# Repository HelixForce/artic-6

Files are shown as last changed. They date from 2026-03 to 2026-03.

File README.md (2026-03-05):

# ARTIC-6 — Voice-Controlled 6-DOF Robotic Arm

> A fully scratch-designed 6-axis robotic arm with 720mm reach, 1kg payload, and natural voice control — built entirely from aluminum plate, stepper motors, and open-source software. No cloud APIs. No subscriptions. Everything runs locally.

<!-- TODO: Replace this line with a screenshot of your Fusion 360 full assembly -->
<!-- ![ARTIC-6 Assembly](docs/render.png) -->






---

## Why ARTIC-6?

Most DIY robot arms top out at 300mm reach with hobby servos that can barely lift a marker. ARTIC-6 is designed for **real tasks** — 720mm of reach and 1kg of payload capacity using industrial NEMA 23 steppers with 10:1 belt reductions. The arm understands plain English commands through local speech recognition and executes them using depth-camera vision and inverse kinematics. No cloud, no API keys, no monthly costs.

---

## Hardware Specs

| Spec | Value |
|---|---|
| Degrees of Freedom | 6 |
| Max Reach | 720mm |
| Payload | 1kg |
| Link 1 (Upper Arm) | 350mm — sandwich: 2× 3mm 6061-T6 Al + 40mm standoffs |
| Link 2 (Forearm) | 280mm — sandwich: 2× 3mm 6061-T6 Al + 40mm standoffs |
| Base Footprint | 250 × 250mm |
| Axes 1-3 Motors | NEMA 23, 1.9Nm, 2.8A + 10:1 GT2 belt reduction |
| Axes 4-6 Motors | NEMA 17, 59Ncm, 2A |
| Drivers | 6× TMC2209 V1.3 (StallGuard + StealthChop) |
| Controller | Arduino Mega 2560 (real-time pulse generation) |
| Brain | Raspberry Pi 5 4GB (motion planning + AI) |
| Base Bearing | 51100 thrust bearing + 608ZZ radial |
| Safety | NC limit switches, hardware E-stop, ±170° hard stops |

---

## Software Stack — 100% Local

```
Voice → Whisper (STT) → Ollama + Llama 3.3 (LLM) → ROS2 + MoveIt2 (IK)
                                    ↑
                    Intel RealSense D435 → YOLO v8 (object detection)
                                    ↓
              Arduino Mega → 6× TMC2209 → 6 Stepper Motors → ARM MOVES
```

Zero cloud. Zero API keys. Zero monthly cost.

---

## Wiring Diagram

Wiring Diagram

[Detailed Wiring & Safety Strategy](./docs/wiring_diagram.pdf) | Full wiring details: [docs/wiring_diagram.md](docs/wiring_diagram.md)

---

## Repository Structure

```
artic-6/
├── bom.csv                 ← Bill of materials with direct shopping links
├── README.md               ← You are here
├── cad/
│   ├── baseplate.dxf       ← 250×250mm base plate (SendCutSend)
│   ├── link1_upper_arm.dxf ← 350mm upper arm plate (order 2×)
│   ├── link2_forearm.dxf   ← 280mm forearm plate (order 2×)
│   ├── thrust_bearing_collar.stl ← 3D print (PETG)
│   └── generate_*.py       ← Python scripts to regenerate CAD files
├── docs/
│   ├── bom.md              ← Detailed BOM with specs and notes
│   ├── build_journal.md    ← Chronological progress log
│   ├── wiring_diagram.md   ← Full wiring strategy
│   ├── wiring_diagram.svg  ← Visual wiring diagram
│   ├── engineering_notes.md← Design decisions and failure analysis
│   └── arm_layout_visual.html ← Interactive arm diagram
├── firmware/
│   └── artic6_firmware/    ← Arduino Mega code (AccelStepper)
│       ├── artic6_firmware.ino
│       ├── config.h        ← Pin defs, speeds, joint limits
│       ├── stepper.h       ← Motor control
│       ├── homing.h        ← Limit switch homing
│       └── serial_protocol.h ← Serial command interface
└── software/               ← Python + ROS2 (in progress)
```

---

## Firmware — Serial Command Interface

The firmware is written and ready to upload. Commands over USB serial at 115200 baud:

```
PING                    → OK PONG
ENABLE                  → OK motors enabled
HOME                    → OK HOME complete
MOVE 2 45.0             → OK MOVE 2 → 45.00  (shoulder to 45°)
MOVA 0 45 -30 0 0 0     → OK MOVA             (all 6 axes)
POS                     → POS 0.00 45.00 -30.00 0.00 0.00 0.00
ESTOP                   → OK ESTOP activated
```

Full command reference: [firmware/README.md](firmware/README.md)

---

## Current Status

| Phase | Status |
|---|---|
| Planning & Engineering Review | ✅ Complete |
| CAD — Flat plates (base, links) | ✅ Generated, audited, imported to Fusion 360 |
| CAD — Joint brackets & motor mounts | 🔄 In progress |
| CAD — Full .STEP assembly | 🔄 In progress |
| Firmware v0.1 | ✅ Complete — AccelStepper, homing, serial protocol |
| Parts ordering | ⏳ Waiting on funds |
| Assembly | ⏳ Pending |
| Software (Python + ROS2) | ⏳ Not started |

---

## Budget

| Category | Cost |
|---|---|
| Motors + Drivers | $84 |
| Gear Reduction (pulleys + belt) | $29 |
| Compute + Electronics | $100 |
| Structure + Hardware (incl. SendCutSend) | $236 |
| Vision + Sensing | $101 |
| Filament (PETG + TPU) | $44 |
| Wiring + Cable Management | $28 |
| **Core Parts Total** | **$622** |
| Tools, shipping, tax, spares | ~$366-$802 |
| **Realistic All-In** | **$988 – $1,424** |

Full BOM with shopping links: [bom.csv](bom.csv) | Detailed specs: [docs/bom.md](docs/bom.md)

---

## Bill of Materials (Summary)

| Qty | Part | Unit ($) | Total ($) |
|-----|---|---|---|
| 3 | NEMA 23 Stepper 1.9Nm 2.8A 8mm shaft | 12 | 36 |
| 3 | NEMA 17 Stepper 2A 59Ncm | 8 | 24 |
| 8 | TMC2209 V1.3 Driver (BTT/Fysetc) | 3 | 24 |
| 4 | GT2 20T Pulley 8mm bore | 1.50 | 6 |
| 2 | GT2 60T Pulley 8mm bore | 3 | 6 |
| 2 | GT2 80T Pulley 8mm bore | 4 | 8 |
| 5m | GT2 Belt PU+steel core 6mm | 1.20 | 6 |
| 1 | Raspberry Pi 5 4GB | 60 | 60 |
| 1 | Arduino Mega 2560 | 8 | 8 |
| 1 | 24V 10A PSU | 12 | 12 |
| 1 | SendCutSend aluminum cutting | 130 | 130 |
| 20 | M5×40mm Hex Standoffs | 0.80 | 16 |
| 20 | 608ZZ Bearings | 0.25 | 5 |
| 2 | 51100 Thrust Bearings | 2 | 4 |
| 1 | RealSense D435 (used, optional) | 90 | 90 |
| — | *All other parts (switches, wire, caps, etc.)* | — | 187 |
| | **Total** | | **$622** |

> Full BOM with direct shopping links: [`bom.csv`](bom.csv)

---

## Documentation

- [Bill of Materials (CSV)](bom.csv) — Every part with qty, price, and shopping link
- [Bill of Materials (detailed)](docs/bom.md) — Full specs, notes, and warnings
- [Build Journal](docs/build_journal.md) — Chronological progress log
- [Wiring Diagram (PDF)](docs/wiring_diagram.pdf) — Printable wiring & safety strategy
- [Wiring Diagram (text)](docs/wiring_diagram.md) — Power zones, star ground, signal chain
- [Engineering Notes](docs/engineering_notes.md) — Lessons learned, failure analysis
- [Firmware README](firmware/README.md) — Setup guide and full command reference

---

## License

MIT License — see [LICENSE](LICENSE)

---

## Author

High school student building a 6-DOF robot arm from scratch for [Hack Club Blueprint](https://hackclub.com/blueprint/).

---

*Built with aluminum, stepper motors, and zero cloud APIs.*

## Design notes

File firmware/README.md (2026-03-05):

# Firmware

Arduino Mega 2560 stepper control code for the ARTIC-6 robot arm.

---

## Setup Instructions

### 1. Install Arduino IDE
Download from [arduino.cc](https://www.arduino.cc/en/software) — use version 2.x.

### 2. Install AccelStepper Library
In Arduino IDE: **Sketch → Include Library → Manage Libraries** → search **"AccelStepper"** by Mike McCauley → **Install**

### 3. Configure Board
- **Tools → Board → Arduino Mega or Mega 2560**
- **Tools → Processor → ATmega2560**
- **Tools → Port → (your COM port)**

### 4. Upload
Open `artic6_firmware/artic6_firmware.ino` → click Upload (→ button).

### 5. Test
Open **Serial Monitor** (magnifying glass icon), set **115200 baud** and **Newline** line ending:
```
Type: PING
Response: OK PONG
```

---

## File Structure

```
firmware/
├── artic6_firmware/
│   ├── artic6_firmware.ino   ← Main sketch (upload this)
│   ├── config.h              ← Pin definitions, speeds, limits, ratios
│   ├── stepper.h             ← Motor control (AccelStepper wrapper)
│   ├── homing.h              ← Limit switch homing sequences
│   └── serial_protocol.h     ← Command parser (RPi ↔ Arduino)
└── README.md                 ← You are here
```

---

## Serial Command Reference

Send commands from RPi (or Serial Monitor) at 115200 baud. Each command is a line ending with `\n`.

| Command | Example | What It Does |
|---|---|---|
| `PING` | `PING` | Heartbeat check → responds `OK PONG` |
| `ENABLE` | `ENABLE` | Energize all motors (they hold position) |
| `DISABLE` | `DISABLE` | De-energize all motors (arm goes limp) |
| `HOME` | `HOME` | Home all 6 axes in safe order |
| `HOMEA <axis>` | `HOMEA 2` | Home single axis (1-6) |
| `MOVE <axis> <deg>` | `MOVE 2 45.0` | Move axis to absolute angle |
| `MOVR <axis> <deg>` | `MOVR 3 -10.5` | Move axis by relative amount |
| `MOVA <a1-a6>` | `MOVA 0 45 -30 0 0 0` | Move all 6 axes simultaneously |
| `POS` | `POS` | Report current joint angles |
| `STATUS` | `STATUS` | Report e-stop, homing, motion state |
| `STOP` | `STOP` | Decelerate all axes to stop |
| `ESTOP` | `ESTOP` | Emergency stop (instant, disables motors) |
| `RESET` | `RESET` | Clear e-stop state (re-home required) |

### Typical Startup Sequence
```
PING          → OK PONG
ENABLE        → OK motors enabled
HOME          → OK HOME complete  (takes ~30 seconds)
MOVE 2 45     → OK MOVE 2 → 45.00
POS           → POS 0.00 45.00 0.00 0.00 0.00 0.00
```

### Response Format
- `OK ...` — command succeeded
- `ERR ...` — command failed (reason given)
- `WARN ...` — non-fatal warning (e.g., limit switch hit)
- `POS ...` — position data
- `STATUS ...` — status data

---

## Hardware Connections

| Arduino Pin | Function | Connected To |
|---|---|---|
| D2-D7 | STEP signals | TMC2209 #1-6 STEP |
| D8-D13 | DIR signals | TMC2209 #1-6 DIR |
| D22-D27 | EN signals | TMC2209 #1-6 EN |
| D28-D33 | Limit switches | KW11-3Z NC terminals |
| A0 | HX711 DOUT | Load cell amplifier |
| A1 | HX711 SCK | Load cell amplifier |
| Serial (USB) | Commands | Raspberry Pi 5 |

---

## How It Works

1. **On power-up:** All motors are disabled (free-spinning). Firmware waits for commands.
2. **ENABLE:** Motors energize and hold position. Arm is stiff but doesn't know where it is.
3. **HOME:** Each axis slowly moves toward its limit switch, backs off, re-approaches slowly for precision, then moves to a known offset. Now the firmware knows exactly where each joint is.
4. **MOVE:** AccelStepper calculates a smooth acceleration/deceleration profile and generates step pulses. The TMC2209 driver converts each pulse into a motor microstep.
5. **Safety:** Limit switches are checked every 100ms during motion. If one triggers, that axis stops immediately. E-stop cuts all motors.

---

## Tuning Guide

All tunable parameters are in `config.h`:

| Parameter | What to Change | When |
|---|---|---|
| `MAX_SPEED_x` | Increase for faster motion | If motors don't skip steps |
| `MAX_ACCEL_x` | Increase for snappier response | If motors don't skip steps |
| `MICROSTEPS` | 8→16 for smoother, 8→4 for faster | Trade smoothness vs speed |
| `REDUCTION_x` | Match your actual pulley ratios | After measuring real hardware |
| `HOME_OFFSETS` | Adjust zero position | After assembly |
| `JOINT_MIN/MAX` | Expand/shrink range of motion | After testing physical limits |

**If a motor skips steps** (makes grinding/clicking noise): reduce `MAX_SPEED` and `MAX_ACCEL` for that axis.

---

## Future: TMC2209 UART Configuration

Not yet implemented. Each TMC2209 needs UART for:
- Setting motor current limit (instead of potentiometer)
- StallGuard4 sensorless homing (backup to limit switches)
- CoolStep power savings

This will be added after basic motion works.

---

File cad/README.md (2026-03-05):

# CAD Files

This folder will contain Fusion 360 project files and DXF exports for SendCutSend.

---

## Planned Files

After Fusion 360 design sessions:

```
cad/
├── artic6.f3d              ← Main Fusion 360 project file
├── base_plate.dxf          ← 250×250mm, thrust bearing seat, slotted motor holes
├── link1_upper_arm.dxf     ← 350mm sandwich plate (make 2)
├── link2_forearm.dxf       ← 280mm sandwich plate (make 2)
├── joint_brackets.dxf      ← Shoulder + elbow pivots
├── motor_mounts.dxf        ← Aluminum L-brackets with slotted holes
└── screenshots/            ← Progress images for documentation
```

---

## CAD Session Order

1. **Base plate** — 250×250mm, slotted NEMA 23 holes, thrust bearing seat (24.5mm OD, 0.5mm deep), cable slot, PSU/electronics mounts, fan bracket, hard stop tabs
2. **Link 1 sandwich plates** (make 2 identical) — 350mm, 8mm pivot holes, M5 standoff holes every 100mm, cable channel, calibration marks at 100mm + 250mm
3. **Link 2 sandwich plates** (make 2 identical) — 280mm, same approach, RealSense strain relief slot
4. **Joint brackets** — shoulder + elbow pivots, hard stop tabs integrated
5. **Motor mounts** — aluminum L-brackets, slotted holes, NEMA 23 bolt pattern (47mm bolt circle, 4× M4)

---

## Key Constraints

| Feature | Dimension | Notes |
|---|---|---|
| Bearing holes | 8.1mm | 8mm + 0.1mm clearance |
| Bolt clearance | nominal + 0.2mm | |
| Slotted holes | 8mm × 14mm | For belt tensioning |
| Thrust bearing seat | 24.5mm OD, 0.5mm deep | NOT 26mm |
| Standoff spacing | Every 100mm max | Prevents bowing |
| Hard stop tabs | ±170° | Prevents cable wind-up |

---

## Exporting for SendCutSend

1. In Fusion 360: Right-click face → "Create Sketch"
2. File → Export → DXF
3. Upload to sendcutsend.com
4. Select: 3mm 6061-T6 Aluminum
5. Get instant quote

---

*CAD files will be added as design progresses*

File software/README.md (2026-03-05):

# Software

Python + ROS2 packages for ARTIC-6 control.

---

## Purpose

This is the "brain" of ARTIC-6. All AI inference runs on the PC, with the Raspberry Pi 5 acting as an executor that forwards commands to the Arduino.

---

## Planned Structure

```
software/
├── voice_pipeline/
│   ├── whisper_stt.py        ← Local speech-to-text
│   └── ollama_brain.py       ← LLM command interpretation
├── vision/
│   ├── realsense_capture.py  ← Depth + RGB from D435
│   ├── yolo_detect.py        ← Object detection
│   └── scene_builder.py      ← 3D scene representation
├── motion/
│   ├── ros2_interface.py     ← ROS2 + MoveIt2 integration
│   └── trajectory_sender.py  ← Send commands to RPi
├── rpi_executor/
│   ├── main.py               ← Runs on RPi 5
│   └── arduino_bridge.py     ← Serial to Arduino Mega
└── README.md                 ← You are here
```

---

## Software Stack

```
Voice
  │
  ▼
Whisper (local STT on PC)
  │
  ▼
Ollama + Llama 3.3 (command interpretation)
  │
  ▼
ROS2 + MoveIt2 (inverse kinematics + motion planning)
  │
  ▼
Python trajectory sender → RPi 5 → Arduino Mega → Motors
```

---

## Dependencies

**PC (Windows 11):**
- Python 3.10+
- Whisper (openai-whisper or faster-whisper)
- Ollama with Llama 3.3 model
- Ultralytics YOLO v8
- pyrealsense2

**Raspberry Pi 5:**
- Python 3.10+
- pyserial
- Flask or FastAPI (for receiving commands from PC)

**Optional (for full ROS2 stack):**
- ROS2 Humble
- MoveIt2

---

## Communication Flow

1. **PC** captures voice → Whisper transcribes
2. **PC** sends text to Ollama → Gets action plan
3. **PC** captures depth frame → YOLO detects objects
4. **PC** calculates trajectory via MoveIt2
5. **PC** sends motion commands to **RPi** (HTTP/WebSocket)
6. **RPi** forwards commands to **Arduino** (USB serial)
7. **Arduino** executes stepper pulses

---

*Software will be developed after firmware is working*

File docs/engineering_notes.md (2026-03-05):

# ARTIC-6 — Engineering Notes

Lessons learned from design review sessions. Reference this before CAD work or ordering parts.

---

## The "Weight vs. Torque" Trap

This is the most common point of failure for scratch-built arms.

**The Problem:** The upper arm (Link 1) is 350mm long. When fully extended horizontally, the shoulder NEMA 23 must lift the weight of the forearm, wrist, gripper, motors for those joints, AND the 1kg payload.

**The Math:** 
- Torque = Force × Distance
- 1kg payload at 720mm reach creates 7.06Nm of torque
- NEMA 23 produces only 0.79Nm

**The Fix:** 10:1 belt reduction minimum on shoulder and elbow joints.

---

## Structural Rigidity

### Single Plate Problem
3mm aluminum is great for weight, but over 350mm it becomes "springy."

**The Fix:** Sandwich construction — two 3mm plates separated by 40mm aluminum standoffs. This creates a box section that resists torsional twist.

### Standoff Placement
**Critical:** Place standoffs every 100mm minimum, not just at ends.

- A 350mm link with only 2 end standoffs will bow and vibrate
- 4 standoffs = every ~90mm — structurally required
- Think of it like a bridge truss: more connection points = stiffer

---

## CAD-Specific Gotchas

### Thrust Bearing Seat
- 51100 thrust bearing has **24mm OD** (not 26mm as originally assumed)
- CAD seat recess: **24.5mm OD, 0.5mm deep**
- If too deep: rotating part rubs against base plate
- If too shallow: bearing not captured, arm slides off-center

### Slotted Motor Mount Holes
- Slots must move **away from joint center**, not side-to-side
- Need 6mm travel to tension GT2 belt
- Without proper tension: massive backlash (slop)
- Slot dimension: 8mm wide × 14mm long

### Bearing Hole Tolerance
- 608ZZ bearing = 8mm ID/OD
- CAD holes: **8.1mm** (8mm + 0.1mm clearance)
- Bolt clearance: nominal + 0.2mm

### Fully Constrained Sketches
- Every Fusion 360 sketch must be fully constrained (no blue lines)
- Blue lines = dimensions can shift unexpectedly
- Lock down everything before extruding

### D-Flat on Motor Shafts
- 20T pulleys use set screws that need a flat spot
- File a D-flat on NEMA 23 shafts before mounting pulleys
- Without flat: set screw on round surface = pulley slips under load = home position drifts

---

## Thermal Management

### TMC2209 Heat
Running NEMA 23 motors at 2.8A generates serious heat on TMC2209 drivers.

**The Fix:**
- Active cooling (dedicated fan) blowing directly over driver heatsinks
- Ensure motor face makes direct flat contact with aluminum mount
- Aluminum link acts as giant heatsink

### PETG Temperature Limits
- PETG softens at 80°C
- NEMA 23 motors can run at 80°C
- **Never mount PETG directly to NEMA 23** — use aluminum mounts only
- PETG is acceptable for: covers, wrist assembly, gripper body (non-structural)

---

## Cable Management

### Internal Routing Trap
"Fully internal cable routing" is professional but dangerous if not planned.

**The Problem:** As Axis 2 (shoulder) rotates, it pinches or pulls wires from Axis 1 (base).

**The Fix:**
- Create "cable race" — rounded internal path where wire can coil/uncoil like clock spring
- Sharp aluminum edges will saw through silicone insulation over time
- 80-100mm service loop at every joint

### Cable Fatigue
Standard copper wire is not meant to bend thousands of times — it work-hardens and snaps.

**The Fix:**
- Use high-flex silicone wire (rated ≥200°C)
- Maximum bend radius as large as possible in CAD
- Never pinch wire at joints

---

## Sensor Placement

### RealSense Minimum Focus
Intel RealSense D435 has a minimum focus distance of ~200mm.

**The Fix:** Don't mount camera so close to gripper that it can't see what it's picking up. Check in CAD.

### RealSense USB-C Strain
Joint movement can destroy the camera's USB-C port.

**The Fix:** Zip-tie strain relief 20mm from camera body.

---

## Electronics Layout

### Star Ground Bus Bar
Mount copper bus bar as close to 24V PSU as possible.

**In CAD:** Include two M4 holes specifically for bus bar mounting. It's the "center of the universe" for all ground wires.

### Logic Converter Placement
TMC2209 drivers generate EMI noise.

**The Fix:** Place logic level converter and RPi 5 on opposite side of enclosure from TMC2209 drivers. Even 50mm separation prevents ghost signals on GPIO.

---

## PETG Bolt Connections

### Fender Washers
Bolting aluminum to PETG requires fender washers.

**Why:** Over time, vibration causes bolts to "creep" through PETG. Fender washers distribute load.

**CAD:** Make bolt head clearance holes wide enough for fender washers.

### Print Orientation
PETG layers pull apart under bolt tension perpendicular to layers.

**The Fix:** Orient prints so bolt tension is parallel to layer lines, not perpendicular.

---

## Safety

### E-Stop
Must be wired to 24V hardware rail (physically disconnects power), NOT a software pin.

If code freezes, you need hardware-level power cutoff.

### Back-EMF Warning
Moving the arm by hand when unpowered can generate back-EMF that destroys TMC2209 drivers.

**Rule:** Never move arm fast when motors are unpowered.

### Limit Switches — NC Wiring
All switches must be **Normally Closed (NC)**, not Normally Open.

**Why:** If a wire breaks (NC open), the system sees it as "triggered" and stops. With NO wiring, a broken wire looks like "not triggered" — arm drives into floor.

---

## Quick Reference Table

| Issue | Consequence | Fix |
|---|---|-----|
| Single plate over 350mm | Arm flexes/shakes | Sandwich construction |
| NEMA 23 direct drive | Can't lift payload | 10:1 belt reduction |
| PETG motor mounts | Melts at 80°C | Aluminum mounts |
| Standard GT2 belt | Backlash/drift | Steel-core GT2 |
| 608ZZ at base | Fails under axial load | 51100 thrust bearing |
| NO limit switches | Wire break = no stop | NC wiring |
| Fixed motor holes | Can't tension belt | Slotted holes |
| Unlimited Axis 1 rotation | Cables snap | ±170° hard stops |
| Daisy-chain grounds | EMI crashes RPi | Star ground |
| Shared USB hub | RealSense starves Arduino | Separate ports |
| 1/256 microstepping | Kills holding torque | Use 1/16 or 1/32 |

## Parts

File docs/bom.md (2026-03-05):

# ARTIC-6 — Bill of Materials v0.3
> Last updated: March 2026  
> **Prioritizing AliExpress for cost efficiency.** Shipping takes 2-4 weeks.  
> Amazon alternatives listed where faster shipping is critical.

---

## Changelog — v0.3
- Switched to AliExpress links where possible (30-50% cheaper)
- Added direct AliExpress search links
- Reduced parts cost from $985 → $622 (core parts only)
- Added realistic all-in cost section ($988-$1,424 including tools, shipping, tax, spares)

## Changelog — v0.2 (corrections from v0.1)

### Critical Fixes
- **NEMA 23 shaft diameter confirmed: 8mm** — specified STEPPERONLINE 23HS30-2804S with explicit 8mm shaft listing. Generic "NEMA 23 2.8A" listings often ship 6.35mm — do NOT order without checking.
- **GT2 80T pulley is aluminum, NOT printed** — found real aluminum 80T 8mm bore on Amazon (ASIN B08NXF2LWZ). Removed "(3D print)" note entirely. Printing the 80T driven pulley under 7Nm would destroy it.
- **Belt strategy changed: open-loop PU+steel-core, not closed-loop** — true closed-loop steel-core GT2 belts do not exist on Amazon in useful lengths. Closed-loop Amazon belts are rubber+fiberglass (more stretch). Correct approach: buy open-loop PU+steel-core white belt by the meter, cut to length, use GT2 belt clamps. Belt lengths still TBD after Fusion 360 center-distance is locked — **do NOT order belts until CAD is done.**
- **Standoff quantity corrected: 4→ 20** — Link 1 (4 standoffs), Link 2 (3 standoffs), base-to-turntable (4 standoffs), joint brackets (4 standoffs), spare (5). Previous BOM qty of 4 would result in a floppy sandwich.
- **51100 thrust bearing OD confirmed: 24mm** — CAD spec said 26mm seat. Correct seat recess: **24.5mm OD, 0.5mm deep**. Fix this in Fusion before DXF export.
- **TMC2209 sourcing: BIGTREETECH V1.3 only** — generic clone TMC2209s have UART pinout differences that will destroy them when wired to Arduino. BTT V1.3 is the verified safe choice.
- **NEMA 17 upsized: 1.5A → 2A, 59Ncm** — the wrist (Axes 4+5) is not as light as assumed when carrying a loaded gripper. Use the 2A 59Ncm STEPPERONLINE version for all 3 NEMA 17 slots.

---

## MOTORS & DRIVERS

| Qty | Part | Where to Buy | Specs | Each | Total |
|-----|---|---|---|---|---|
| 3 | **NEMA 23 Stepper — 1.9Nm, 2.8A, 8mm shaft** | [AliExpress](https://www.aliexpress.com/w/wholesale-nema-23-stepper-2.8a-8mm-shaft.html) | 57×57×76mm, 8mm D-shaft, 4-wire bipolar. **VERIFY 8mm shaft before buying** | $12 | $36 |
| 3 | **NEMA 17 Stepper — 2A, 59Ncm, 5mm shaft** | [AliExpress](https://www.aliexpress.com/w/wholesale-nema-17-stepper-59ncm.html) | 42×42×48mm, 1.8°, 4-wire bipolar | $8 | $24 |
| 8 | **TMC2209 V1.3 Driver** | [AliExpress](https://www.aliexpress.com/w/wholesale-tmc2209-v1.3-bigtreetech.html) | BTT or Fysetc brand. 2A cont, StallGuard4, UART. **Avoid generic clones** | $3 | $24 |

> ⚠️ **CRITICAL:** Verify NEMA 23 has 8mm shaft (not 6.35mm). Check listing photos for shaft diameter. BTT/Fysetc TMC2209 only — generic clones have wrong UART pinout.

**Motors + Drivers Subtotal: $84** *(was $166 on Amazon)*

---

## GEAR REDUCTION — ALL ALUMINUM — NO PRINTED PULLEYS

> 10:1 minimum on Axis 2 (shoulder) and Axis 3 (elbow).  
> 20T (motor) → 80T (joint) = **4:1 per stage**. Two stages = 16:1 theoretical, ~10-12:1 effective.

| Qty | Part | Where to Buy | Notes | Each | Total |
|-----|---|---|---|---|---|
| 4 | **GT2 20T Pulley — 8mm bore, aluminum** | [AliExpress](https://www.aliexpress.com/w/wholesale-gt2-20t-pulley-8mm-bore-aluminum.html) | Fits NEMA 23 8mm shaft | $1.50 | $6 |
| 2 | **GT2 60T Pulley — 8mm bore, aluminum** | [AliExpress](https://www.aliexpress.com/w/wholesale-gt2-60t-pulley-8mm-bore.html) | 6mm belt width | $3 | $6 |
| 2 | **GT2 80T Pulley — 8mm bore, aluminum** | [AliExpress](https://www.aliexpress.com/w/wholesale-gt2-80t-pulley-8mm-bore-aluminum.html) | **Must be aluminum, NOT 3D printed** | $4 | $8 |
| 5m | **GT2 Open Belt — PU + steel core, 6mm** | [AliExpress](https://www.aliexpress.com/w/wholesale-gt2-belt-steel-core-6mm-open.html) | White PU, cut to length. **Order after CAD done** | $6 | $6 |
| 1 | **GT2 Belt Clamp Kit** | [AliExpress](https://www.aliexpress.com/w/wholesale-gt2-belt-clamp-6mm.html) | Copper buckles for open-loop ends | $3 | $3 |

> ⚠️ **Belt length:** Order after CAD is complete. Formula: Belt = 2×center_distance + π×(R_large + R_small)

**Gear Reduction Subtotal: $29** *(was $56 on Amazon)*

---

## COMPUTE & ELECTRONICS

| Qty | Part | Where to Buy | Notes | Each | Total |
|-----|---|---|---|---|---|
| 1 | **Raspberry Pi 5 — 4GB** | [PiShop.us](https://www.pishop.us/) | Stock varies. Check PiShop first | $60 | $60 |
| 1 | **Arduino Mega 2560 Clone** | [AliExpress](https://www.aliexpress.com/w/wholesale-arduino-mega-2560-atmega16u2.html) | Get ATmega16U2 USB chip (not CH340) | $8 | $8 |
| 1 | **24V 10A DC PSU** | [AliExpress](https://www.aliexpress.com/w/wholesale-24v-10a-switching-power-supply.html) | 240W minimum | $12 | $12 |
| 1 | **5V 3A USB-C PSU (RPi)** | [AliExpress](https://www.aliexpress.com/w/wholesale-5v-3a-usb-c-power-supply.html) | Dedicated for RPi5 only | $6 | $6 |
| 1 | **22mm E-Stop Button — NC** | [AliExpress](https://www.aliexpress.com/w/wholesale-22mm-emergency-stop-button-NC.html) | Red mushroom, twist-release, **must be NC** | $3 | $3 |
| 10 | **KW11-3Z Limit Switch — SPDT** | [AliExpress](https://www.aliexpress.com/w/wholesale-kw11-3z-limit-switch.html) | Wire to NC terminal only | $0.30 | $3 |
| 1 | **8-Ch Opto-Isolated Relay** | [AliExpress](https://www.aliexpress.com/w/wholesale-8-channel-relay-opto-isolated-5v.html) | Must be opto-isolated | $4 | $4 |
| 1 | **Logic Level Converter 4-ch** | [AliExpress](https://www.aliexpress.com/w/wholesale-logic-level-converter-3.3v-5v-bidirectional.html) | 3.3V ↔ 5V bidirectional | $1 | $1 |
| 5 | **1000µF 35V Capacitor** | [AliExpress](https://www.aliexpress.com/w/wholesale-1000uf-35v-electrolytic-capacitor.html) | One per NEMA 23 driver + spares | $0.20 | $1 |
| 1 | **Ferrite Core Kit** | [AliExpress](https://www.aliexpress.com/w/wholesale-ferrite-bead-kit-usb-cable.html) | Snap-on type | $2 | $2 |

> ⚠️ **Limit switch wiring:** KW11-3Z has COM, NO, NC pins. Wire COM→+5V, NC→Arduino pin with 10kΩ pulldown. Wire break = pin goes LOW = arm stops (fail-safe).

**Compute + Electronics Subtotal: $100** *(was $165 on Amazon)*

---

## STRUCTURE & HARDWARE

| Qty | Part | Where to Buy | Notes | Each | Total |
|-----|---|---|---|---|---|
| 1 | **SendCutSend — 3mm 6061-T6 Al** | [sendcutsend.com](https://sendcutsend.com/) | Base plate, 2× Link1, 2× Link2, brackets, mounts | — | $185 |
| 2 | **51100 Thrust Bearing (10×24×9mm)** | [AliExpress](https://www.aliexpress.com/w/wholesale-51100-thrust-bearing.html) | 10mm bore, 24mm OD. 1 spare | $2 | $4 |
| 20 | **M5 × 40mm Aluminum Standoffs** | [AliExpress](https://www.aliexpress.com/w/wholesale-m5-aluminum-standoff-40mm-hex.html) | Hex, male-female | $0.80 | $16 |
| 1 | **M3/M4/M5 Bolt & Nut Kit (500pc)** | [AliExpress](https://www.aliexpress.com/w/wholesale-metric-bolt-assortment-m3-m4-m5.html) | Socket head cap screws | $8 | $8 |
| 1 | **Brass Heat-Set Insert Kit** | [AliExpress](https://www.aliexpress.com/w/wholesale-heat-set-insert-m3-m4-brass.html) | M3/M4 for PETG parts | $5 | $5 |
| 20 | **608ZZ Bearings** | [AliExpress](https://www.aliexpress.com/w/wholesale-608zz-bearing.html) | 8×22×7mm. Buy 20, need 12 | $0.25 | $5 |
| 6 | **8mm Rigid Shaft Coupler** | [AliExpress](https://www.aliexpress.com/w/wholesale-8mm-rigid-shaft-coupler-aluminum.html) | Aluminum | $1.50 | $9 |
| 1 | **Fender Washer Kit — M3/M4/M5** | [AliExpress](https://www.aliexpress.com/w/wholesale-fender-washer-assortment-metric.html) | Under bolts touching PETG | $4 | $4 |

> ⚠️ **Standoff placement:** Every 100mm minimum. A 350mm link with only end standoffs will bow.

**Structure + Hardware Subtotal: $236** *(was $301 on Amazon — SendCutSend same price)*

---

## VISION & SENSING

| Qty | Part | Where to Buy | Notes | Each | Total |
|-----|---|---|---|---|---|
| 1 | **Intel RealSense D435 — used** | [eBay](https://www.ebay.com/sch/i.html?_nkw=intel+realsense+d435) | Target $80-100 used. Check USB-C port | $90 | $90 |
| 1 | **1kg Load Cell + HX711** | [AliExpress](https://www.aliexpress.com/w/wholesale-1kg-load-cell-hx711.html) | Tare every grip cycle | $3 | $3 |
| 1 | **USB Microphone** | [AliExpress](https://www.aliexpress.com/w/wholesale-usb-microphone-mini.html) | Must be USB (RPi5 has no analog audio) | $8 | $8 |

**Vision + Sensing Subtotal: $101** *(was $130)*

---

## FILAMENT

> PETG: covers, housings, wrist assembly, gripper body only. No structural PETG near motors.

| Qty | Part | Where to Buy | Notes | Each | Total |
|-----|---|---|---|---|---|
| 3 | **PETG Filament — 1kg** | [AliExpress](https://www.aliexpress.com/w/wholesale-petg-filament-1kg.html) | 230-240°C print temp | $12 | $36 |
| 1 | **TPU 95A Filament — 500g** | [AliExpress](https://www.aliexpress.com/w/wholesale-tpu-95a-filament-500g.html) | Gripper fingertips only | $8 | $8 |

**Filament Subtotal: $44** *(was $82)*

---

## WIRING & CABLE MANAGEMENT

| Qty | Part | Where to Buy | Notes | Each | Total |
|-----|---|---|---|---|---|
| 1 | **Silicone Wire Kit — 22/26AWG** | [AliExpress](https://www.aliexpress.com/w/wholesale-silicone-wire-kit-22awg-26awg.html) | High-flex, ≥200°C rated | $6 | $6 |
| 5m | **Shielded Twisted Pair — 24AWG** | [AliExpress](https://www.aliexpress.com/w/wholesale-shielded-twisted-pair-24awg.html) | For limit switches | $4 | $4 |
| 1 | **JST-XH Connector Kit** | [AliExpress](https://www.aliexpress.com/w/wholesale-jst-xh-connector-kit.html) | 2.54mm pitch | $4 | $4 |
| 1 | **Cable Drag Chain — 10×15mm, 1m** | [AliExpress](https://www.aliexpress.com/w/wholesale-cable-drag-chain-10x15.html) | Check bend radius | $4 | $4 |
| 1 | **Braided Cable Sleeve Kit** | [AliExpress](https://www.aliexpress.com/w/wholesale-braided-cable-sleeve-assortment.html) | | $3 | $3 |
| 1 | **Heat Shrink Tubing Kit** | [AliExpress](https://www.aliexpress.com/w/wholesale-heat-shrink-tubing-assortment.html) | | $2 | $2 |
| 1 | **Copper Ground Bus Bar** | [AliExpress](https://www.aliexpress.com/w/wholesale-ground-bus-bar-copper-10-way.html) | Star ground point | $3 | $3 |
| 1 | **12-Way Terminal Block** | [AliExpress](https://www.aliexpress.com/w/wholesale-terminal-block-12-way-10a.html) | Power distribution | $2 | $2 |

**Wiring Subtotal: $28** *(was $85)*

---

## REALISTIC ALL-IN COST

> **This is the honest total** — including tools, shipping, tax, consumables, and contingency.
> Most BOMs hide these. I'm not hiding anything.

### Parts List (Core Components)

| Category | Low Est. | High Est. |
|---|---|---|
| Core Parts (Motors, Electronics, Structure) | $580 | $640 |
| 3D Printing Filament (PETG + TPU) | $60 | $82 |
| SendCutSend Aluminum Cutting | $110 | $150 |
| **Parts Subtotal** | **$750** | **$872** |

### Hidden & Missed Costs (What Most BOMs Don't Show)

| Category | Low Est. | High Est. |
|---|---|---|
| Shipping — AliExpress | $18 | $35 |
| Shipping — Amazon | $0 | $20 |
| Sales Tax (~8%) | $45 | $70 |
| Tools (soldering iron, multimeter, crimpers) | $0 | $132 |
| Consumables (solder, flux, threadlocker, grease) | $33 | $58 |
| RPi Essentials (SD card, cooler, USB hub) | $30 | $48 |
| Prototyping (breadboard, jumpers, caps) | $17 | $28 |
| Installation (desk mount, velcro) | $14 | $25 |
| **Hidden Costs Subtotal** | **$157** | **$416** |

### Spares & Contingency

| Item | Low Est. | High Est. |
|---|---|---|
| Spare NEMA 17 Motor (1x) | $12 | $12 |
| Spare TMC2209 Driver (2x) | $14 | $14 |
| DOA / Wrong Parts | $20 | $40 |
| Failed Prints / Wasted Filament | $15 | $30 |
| Oops Fund | $20 | $40 |
| **Spares & Contingency Subtotal** | **$81** | **$136** |

---

## 💰 GRAND TOTAL — REALISTIC

| | Low | High |
|--|-----|---|
| Parts List (accounted) | $750 | $872 |
| Hidden / Missed Costs | $157 | $416 |
| Spares & Contingency | $81 | $136 |
| **GRAND TOTAL** | **$988** | **$1,424** |

> If you own tools already (soldering iron, multimeter, wire strippers): subtract ~$100.
> Realistic midpoint estimate: **~$1,100-$1,200**.

---

## Phased Buying Plan

| Phase | What | Cost | When |
|---|---|---|---|
| **1** | Fusion 360 Design | FREE | Month 1 |
| **2** | Structure & Motors | $434 | Month 1-2 |
| **3** | Electronics & Power | $147 | Month 2 |
| **4** | Brain & Senses | $268 | Month 2-3 |
| **5** | Tools, Consumables, Spares | $223 | Ongoing |
| | **TOTAL** | **$1,072** | |

---

## Blueprint Grant Request: $350

**I'm not asking for the full $1,100. I'm asking for $350 to cover Phase 2 motion components.**

| What Grant Covers | Cost |
|---|---|
| 3× NEMA 23 Steppers | $36 |
| 3× NEMA 17 Steppers | $24 |
| 6× TMC2209 Drivers | $24 |
| GT2 Pulleys + Belt | $42 |
| Bolts, bearings, standoffs | $42 |
| Wiring supplies | $28 |
| Shipping (AliExpress) | $35 |
| Buffer for price changes | $119 |
| **Grant Request** | **$350** |

### What I'm Self-Funding

| What I Pay For | Cost |
|---|---|
| SendCutSend aluminum | $130 |
| Raspberry Pi 5 (4GB) | $60 |
| Intel RealSense D435 (used) | $95 |
| RPi essentials (SD, cooler, hub) | $46 |
| 24V PSU + Arduino + E-stop | $57 |
| Filament (PETG + TPU) | $82 |
| All tools (soldering, etc.) | $55 |
| All consumables | $58 |
| Spares & contingency | $136 |
| **My Contribution** | **~$719** |

> **Total project: ~$1,100 | Grant: $350 | Self-funded: ~$750**
> I'm covering 68% of the project myself.

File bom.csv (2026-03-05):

Qty | Part | Category | Specs | Unit Price (USD) | Total (USD) | Link
3 | NEMA 23 Stepper Motor 1.9Nm 2.8A 8mm shaft | Motors & Drivers | 57x57x76mm, 8mm D-shaft, 4-wire bipolar | 12.00 | 36.00 | https://www.aliexpress.com/w/wholesale-nema-23-stepper-2.8a-8mm-shaft.html
3 | NEMA 17 Stepper Motor 2A 59Ncm 5mm shaft | Motors & Drivers | 42x42x48mm, 1.8deg, 4-wire bipolar | 8.00 | 24.00 | https://www.aliexpress.com/w/wholesale-nema-17-stepper-59ncm.html
8 | TMC2209 V1.3 Stepper Driver | Motors & Drivers | BTT or Fysetc brand, 2A continuous, StallGuard4, UART | 3.00 | 24.00 | https://www.aliexpress.com/w/wholesale-tmc2209-v1.3-bigtreetech.html
4 | GT2 20T Pulley 8mm bore aluminum | Gear Reduction | Fits NEMA 23 8mm shaft | 1.50 | 6.00 | https://www.aliexpress.com/w/wholesale-gt2-20t-pulley-8mm-bore-aluminum.html
2 | GT2 60T Pulley 8mm bore aluminum | Gear Reduction | 6mm belt width | 3.00 | 6.00 | https://www.aliexpress.com/w/wholesale-gt2-60t-pulley-8mm-bore.html
2 | GT2 80T Pulley 8mm bore aluminum | Gear Reduction | Must be aluminum not 3D printed | 4.00 | 8.00 | https://www.aliexpress.com/w/wholesale-gt2-80t-pulley-8mm-bore-aluminum.html
5 | GT2 Open Belt PU steel core 6mm (meters) | Gear Reduction | White PU, cut to length | 1.20 | 6.00 | https://www.aliexpress.com/w/wholesale-gt2-belt-steel-core-6mm-open.html
1 | GT2 Belt Clamp Kit | Gear Reduction | Copper buckles for open-loop ends | 3.00 | 3.00 | https://www.aliexpress.com/w/wholesale-gt2-belt-clamp-6mm.html
1 | Raspberry Pi 5 4GB | Compute & Electronics | Executor — receives commands from PC | 60.00 | 60.00 | https://www.pishop.us/
1 | Arduino Mega 2560 Clone | Compute & Electronics | ATmega16U2 USB chip (not CH340) | 8.00 | 8.00 | https://www.aliexpress.com/w/wholesale-arduino-mega-2560-atmega16u2.html
1 | 24V 10A DC Power Supply | Compute & Electronics | 240W minimum switching PSU | 12.00 | 12.00 | https://www.aliexpress.com/w/wholesale-24v-10a-switching-power-supply.html
1 | 5V 3A USB-C Power Supply | Compute & Electronics | Dedicated for RPi5 only | 6.00 | 6.00 | https://www.aliexpress.com/w/wholesale-5v-3a-usb-c-power-supply.html
1 | 22mm E-Stop Button NC | Compute & Electronics | Red mushroom, twist-release, normally closed | 3.00 | 3.00 | https://www.aliexpress.com/w/wholesale-22mm-emergency-stop-button-NC.html
10 | KW11-3Z Limit Switch SPDT | Compute & Electronics | Wire to NC terminal only — fail-safe | 0.30 | 3.00 | https://www.aliexpress.com/w/wholesale-kw11-3z-limit-switch.html
1 | 8-Channel Opto-Isolated Relay Board | Compute & Electronics | Must be opto-isolated | 4.00 | 4.00 | https://www.aliexpress.com/w/wholesale-8-channel-relay-opto-isolated-5v.html
1 | Logic Level Converter 4-ch bidirectional | Compute & Electronics | 3.3V to 5V bidirectional | 1.00 | 1.00 | https://www.aliexpress.com/w/wholesale-logic-level-converter-3.3v-5v-bidirectional.html
5 | 1000uF 35V Electrolytic Capacitor | Compute & Electronics | One per NEMA 23 driver plus spares | 0.20 | 1.00 | https://www.aliexpress.com/w/wholesale-1000uf-35v-electrolytic-capacitor.html
1 | Ferrite Core Kit snap-on | Compute & Electronics | Snap-on type for USB cables | 2.00 | 2.00 | https://www.aliexpress.com/w/wholesale-ferrite-bead-kit-usb-cable.html
1 | SendCutSend 3mm 6061-T6 Aluminum | Structure & Hardware | Base plate, 2x Link1, 2x Link2, brackets, mounts | 130.00 | 130.00 | https://sendcutsend.com/
2 | 51100 Thrust Bearing 10x24x9mm | Structure & Hardware | 10mm bore, 24mm OD, 1 spare | 2.00 | 4.00 | https://www.aliexpress.com/w/wholesale-51100-thrust-bearing.html
20 | M5 x 40mm Aluminum Hex Standoff | Structure & Hardware | Hex, male-female | 0.80 | 16.00 | https://www.aliexpress.com/w/wholesale-m5-aluminum-standoff-40mm-hex.html
1 | M3 M4 M5 Bolt and Nut Kit 500pc | Structure & Hardware | Socket head cap screws | 8.00 | 8.00 | https://www.aliexpress.com/w/wholesale-metric-bolt-assortment-m3-m4-m5.html
1 | Brass Heat-Set Insert Kit | Structure & Hardware | M3 M4 for PETG printed parts | 5.00 | 5.00 | https://www.aliexpress.com/w/wholesale-heat-set-insert-m3-m4-brass.html
20 | 608ZZ Bearing 8x22x7mm | Structure & Hardware | Buy 20, need 12 | 0.25 | 5.00 | https://www.aliexpress.com/w/wholesale-608zz-bearing.html
6 | 8mm Rigid Shaft Coupler aluminum | Structure & Hardware | Aluminum coupler | 1.50 | 9.00 | https://www.aliexpress.com/w/wholesale-8mm-rigid-shaft-coupler-aluminum.html
1 | Fender Washer Kit M3 M4 M5 | Structure & Hardware | Under bolts touching PETG | 4.00 | 4.00 | https://www.aliexpress.com/w/wholesale-fender-washer-assortment-metric.html
1 | Intel RealSense D435 (used) | Vision & Sensing | Check USB-C port condition, target $80-100 | 90.00 | 90.00 | https://www.ebay.com/sch/i.html?_nkw=intel+realsense+d435
1 | 1kg Load Cell with HX711 Amplifier | Vision & Sensing | Tare every grip cycle | 3.00 | 3.00 | https://www.aliexpress.com/w/wholesale-1kg-load-cell-hx711.html
1 | USB Microphone | Vision & Sensing | Must be USB — RPi5 has no analog audio in | 8.00 | 8.00 | https://www.aliexpress.com/w/wholesale-usb-microphone-mini.html
3 | PETG Filament 1kg spool | Filament | 230-240C nozzle, structural covers and wrist only | 12.00 | 36.00 | https://www.aliexpress.com/w/wholesale-petg-filament-1kg.html
1 | TPU 95A Filament 500g spool | Filament | Gripper fingertips only | 8.00 | 8.00 | https://www.aliexpress.com/w/wholesale-tpu-95a-filament-500g.html
1 | Silicone Wire Kit 22AWG 26AWG | Wiring & Cables | High-flex, 200C+ rated | 6.00 | 6.00 | https://www.aliexpress.com/w/wholesale-silicone-wire-kit-22awg-26awg.html
5 | Shielded Twisted Pair 24AWG (meters) | Wiring & Cables | For limit switch runs | 0.80 | 4.00 | https://www.aliexpress.com/w/wholesale-shielded-twisted-pair-24awg.html
1 | JST-XH Connector Kit | Wiring & Cables | 2.54mm pitch | 4.00 | 4.00 | https://www.aliexpress.com/w/wholesale-jst-xh-connector-kit.html
1 | Cable Drag Chain 10x15mm 1m | Wiring & Cables | Check bend radius fits wire bundle | 4.00 | 4.00 | https://www.aliexpress.com/w/wholesale-cable-drag-chain-10x15.html
1 | Braided Cable Sleeve Kit | Wiring & Cables | Assorted sizes | 3.00 | 3.00 | https://www.aliexpress.com/w/wholesale-braided-cable-sleeve-assortment.html
1 | Heat Shrink Tubing Kit | Wiring & Cables | Assorted sizes | 2.00 | 2.00 | https://www.aliexpress.com/w/wholesale-heat-shrink-tubing-assortment.html
1 | Copper Ground Bus Bar 10-way | Wiring & Cables | Star ground point | 3.00 | 3.00 | https://www.aliexpress.com/w/wholesale-ground-bus-bar-copper-10-way.html
1 | 12-Way Terminal Block 10A | Wiring & Cables | Power distribution | 2.00 | 2.00 | https://www.aliexpress.com/w/wholesale-terminal-block-12-way-10a.html

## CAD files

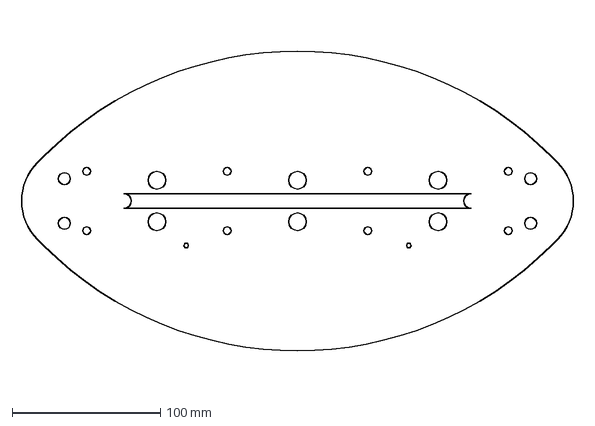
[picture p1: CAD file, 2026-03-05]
cad/link1_upper_arm.dxf
378.7 x 248.9 mm

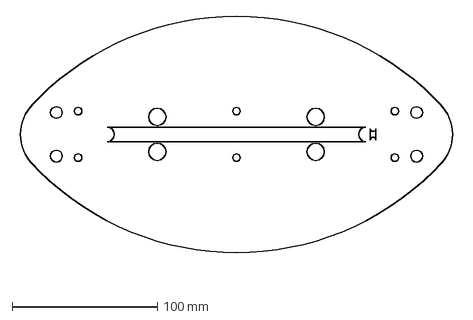
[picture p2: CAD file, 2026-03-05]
cad/link2_forearm.dxf
303.2 x 181.4 mm

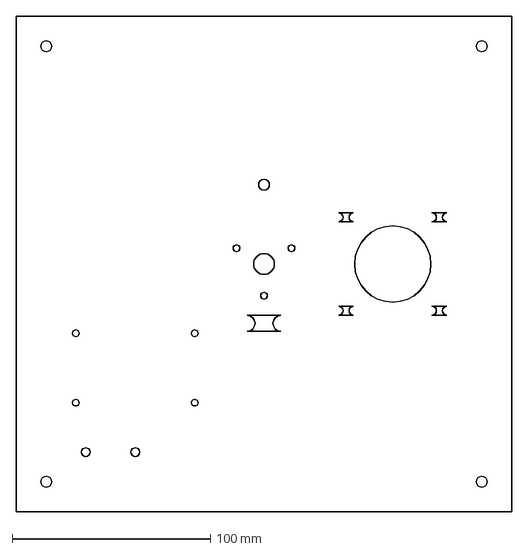
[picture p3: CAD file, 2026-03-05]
cad/baseplate.dxf
250.0 x 250.0 mm

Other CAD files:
cad/thrust_bearing_collar.stl

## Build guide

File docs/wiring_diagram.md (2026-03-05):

# ARTIC-6 — Wiring Strategy

---

## Changelog — v0.1
- Added two-zone layout (Power Zone vs Logic Zone — 50mm minimum separation)
- Added star grounding requirement — heavy gauge copper bus bar
- Specified opto-isolated relay board (not standard relay)
- Added NC wiring for all 6 limit switches
- Added shielded twisted pair for limit switch runs
- Specified USB port assignment: RealSense → USB3 (blue), Arduino → USB2 (black)
- Added capacitor buffer on relay board 5V input
- Added ferrite bead on Arduino–RPi USB cable
- E-stop wired to 24V hardware rail (not software pin)
- Added staggered relay trigger timing note (50ms delay between each)

---

## Zone Layout

```
┌─────────────────────────────────────────────────────┐
│                   BASE ENCLOSURE                    │
│                                                     │
│  ┌──────────────────┐   50mm+  ┌─────────────────┐ │
│  │   POWER ZONE     │  ──────  │   LOGIC ZONE    │ │
│  │                  │          │                 │ │
│  │  24V 10A PSU     │          │  Raspberry Pi 5 │ │
│  │  6× TMC2209      │          │  Arduino Mega   │ │
│  │  8ch Relay Board │          │  Logic Converter│ │
│  │  Ground Bus Bar  │          │  5V USB-C PSU   │ │
│  └──────────────────┘          └─────────────────┘ │
│                                                     │
│  E-STOP ──────────────────────── 24V MAIN RAIL     │
└─────────────────────────────────────────────────────┘
```

**Rule:** Never bundle 24V motor wires next to 3.3V signal wires.

---

## Power Distribution

```
Wall AC
  │
  ▼
24V 10A PSU ──── E-STOP (hardware, cuts 24V rail entirely)
  │
  ├──► TMC2209 #1 (NEMA 23 — Axis 1, base rotation)
  ├──► TMC2209 #2 (NEMA 23 — Axis 2, shoulder)
  ├──► TMC2209 #3 (NEMA 23 — Axis 3, elbow)
  ├──► TMC2209 #4 (NEMA 17 — Axis 4, wrist pitch)
  ├──► TMC2209 #5 (NEMA 17 — Axis 5, wrist roll)
  └──► TMC2209 #6 (NEMA 17 — Axis 6, gripper)

5V 3A USB-C PSU (dedicated, separate from 24V)
  └──► Raspberry Pi 5 only — never share with motors
```

---

## Star Ground

```
NEMA 23 #1 ground ──┐
NEMA 23 #2 ground ──┤
NEMA 23 #3 ground ──┤
NEMA 17 #4 ground ──┼──► COPPER BUS BAR ──► PSU negative terminal
NEMA 17 #5 ground ──┤    (star ground)
NEMA 17 #6 ground ──┤
Arduino ground ─────┤
RPi ground ─────────┘
```

Never daisy-chain grounds. Motor return current must NOT flow through RPi ground plane.

---

## Signal Chain

```
RPi 5 GPIO (3.3V)
  │
  ▼
Logic Level Converter (bi-directional 3.3V ↔ 5V)
  │
  ▼
Arduino Mega (5V) ──── USB 2.0 (black port) ──── RPi USB hub
  │                    [ferrite bead on cable]
  ├──► STEP/DIR/EN ──► TMC2209 #1–6
  ├──► Limit Switch inputs (6×, NC wired, shielded twisted pair)
  └──► HX711 (load cell amp) → SPI

RealSense D435 ──── USB 3.0 (blue port, direct to RPi) ──── RPi 5
                    [do not share hub with Arduino]
```

---

## Limit Switch Wiring (NC — Fail-Safe)

```
+5V ────────────────┬─────┬─────┬─────┬─────┬─────┐
                    │     │     │     │     │     │
                   SW1   SW2   SW3   SW4   SW5   SW6
                   (NC)  (NC)  (NC)  (NC)  (NC)  (NC)
                    │     │     │     │     │     │
Arduino Pin ───────┼─────┼─────┼─────┼─────┼─────┤
                    │     │     │     │     │     │
                   10k   10k   10k   10k   10k   10k  (pull-down)
                    │     │     │     │     │     │
GND ───────────────┴─────┴─────┴─────┴─────┴─────┘
```

**Logic:**
- Normal state (switch closed): Pin reads HIGH (5V through NC contact)
- Triggered OR wire break: Pin reads LOW (pull-down to GND)
- LOW = STOP immediately — this is fail-safe

---

## EMI Prevention Checklist

- [ ] Ferrite bead on Arduino ↔ RPi USB cable
- [ ] 1000µF cap on each NEMA 23 TMC2209 power input
- [ ] 1000µF cap on relay board 5V input
- [ ] Twist motor wire pairs (A+/A- together, B+/B- together)
- [ ] Shielded twisted pair for all limit switch runs
- [ ] Shield connected to star ground at ONE end only (PSU side)
- [ ] 50mm+ separation between power zone and logic zone
- [ ] RPi powered from dedicated 5V 3A PSU (not buck converter)

---

## E-Stop Wiring

```
24V PSU (+) ─────────┐
                     │
              ┌──────┴──────┐
              │   E-STOP    │  ← 22mm NC mushroom button
              │   (NC)      │
              └──────┬──────┘
                     │
24V RAIL ────────────┘  ← Powers all TMC2209 drivers

When E-STOP pressed:
- 24V rail goes dead instantly
- All motors lose power
- Arm stops (may fall — keep hand nearby)
```

**Important:** E-stop is hardware-level, not software. It physically disconnects 24V regardless of code state.

---

## Relay Board Trigger Timing

When activating multiple relays (e.g., at startup), stagger triggers by 50ms:

```python
# In Arduino or Python
for i in range(6):
    activate_relay(i)
    delay(50)  # ms — prevents inrush current spike
```

This prevents PSU voltage sag from simultaneous relay coil activation.

---

## USB Port Assignment (RPi 5)

| Port | Color | Device | Why |
|---|---|---|-----|
| USB 3.0 | Blue | RealSense D435 | High bandwidth (depth + RGB stream) |
| USB 2.0 | Black | Arduino Mega | Low bandwidth (serial commands only) |
| USB 2.0 | Black | USB Microphone | Low bandwidth (audio) |

**Rule:** RealSense must be on USB 3.0 blue port or it will drop frames. Never put Arduino and RealSense on same hub.

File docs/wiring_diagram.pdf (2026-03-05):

wiring_diagram.md | 2026-03-05

# ARTIC-6 — Wiring Strategy

## Changelog — v0.1

Added two-zone layout (Power Zone vs Logic Zone — 50mm minimum separation) Added star grounding requirement — heavy gauge copper bus bar
Specified opto-isolated relay board (not standard relay)
Added NC wiring for all 6 limit switches
Added shielded twisted pair for limit switch runs
Specified USB port assignment: RealSense → USB3 (blue), Arduino → USB2 (black) Added capacitor buffer on relay board 5V input
Added ferrite bead on Arduino–RPi USB cable
E-stop wired to 24V hardware rail (not software pin)
Added staggered relay trigger timing note (50ms delay between each)

## Zone Layout

┌─────────────────────────────────────────────────────┐
│ | BASE ENCLOSURE | │
│ | │
│ ┌──────────────────┐ | 50mm+ ┌─────────────────┐ │
│ │ | POWER ZONE | │ ────── │ | LOGIC ZONE | │ │
│ │ | │ | │ | │ │
│ │ 24V 10A PSU | │ | │ Raspberry Pi 5 │ │
│ │ 6× TMC2209 | │ | │ Arduino Mega | │ │
│ │ 8ch Relay Board │ | │ Logic Converter│ │
│ │ Ground Bus Bar │ | │ 5V USB-C PSU | │ │
│ └──────────────────┘ | └─────────────────┘ │
│ | │
│ E-STOP ──────────────────────── 24V MAIN RAIL | │
└─────────────────────────────────────────────────────┘

Rule: Never bundle 24V motor wires next to 3.3V signal wires.

## Power Distribution

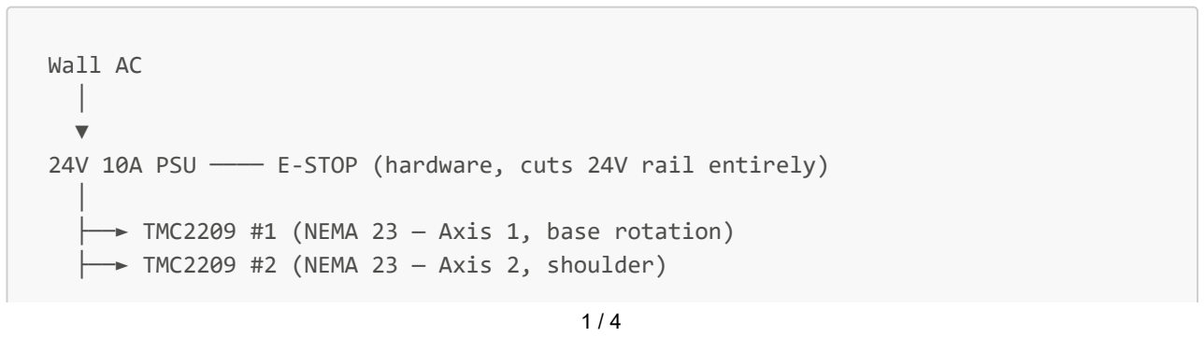
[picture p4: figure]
Wall AC │ ▼

24V 10A PSU ──── E-STOP (hardware, cuts 24V rail entirely)

├──► TMC2209 #1 (NEMA 23 — Axis 1, base rotation)
├──► TMC2209 #2 (NEMA 23 — Axis 2, shoulder)

## Star Ground

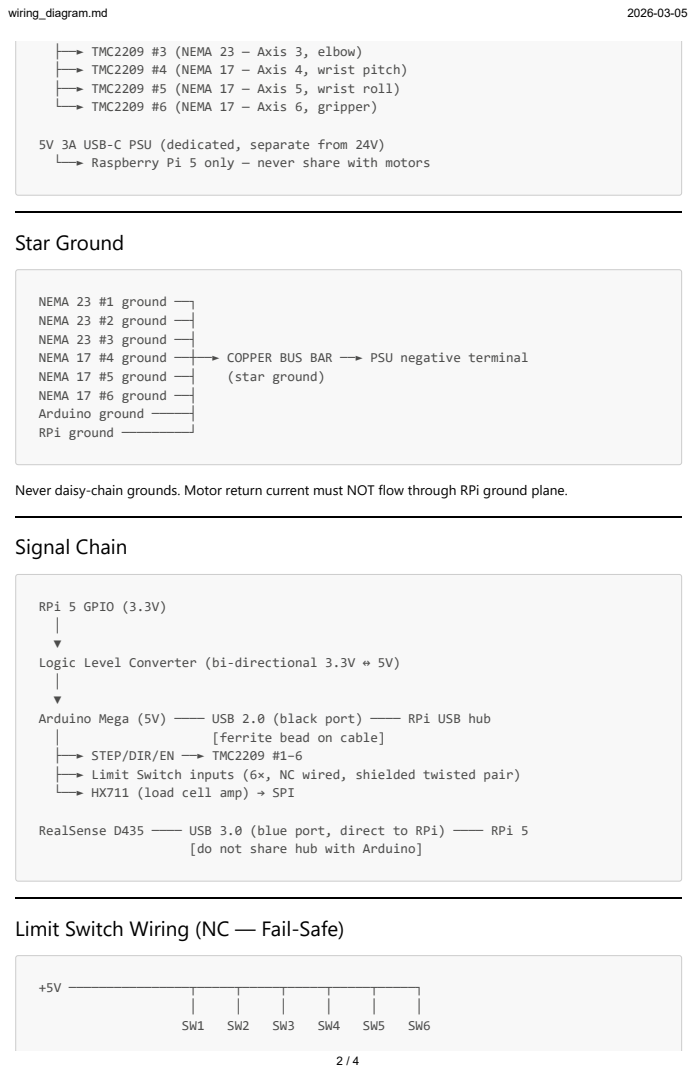
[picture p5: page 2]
NEMA 17 #5 ground ──┤; (star ground); Signal Chain; [ferrite bead on cable]

├──► TMC2209 #3 (NEMA 23 — Axis 3, elbow)
├──► TMC2209 #4 (NEMA 17 — Axis 4, wrist pitch)
├──► TMC2209 #5 (NEMA 17 — Axis 5, wrist roll)
└──► TMC2209 #6 (NEMA 17 — Axis 6, gripper)

5V 3A USB-C PSU (dedicated, separate from 24V)
└──► Raspberry Pi 5 only — never share with motors

NEMA 23 #1 ground ──┐
NEMA 23 #2 ground ──┤
NEMA 23 #3 ground ──┤
NEMA 17 #4 ground ──┼──► COPPER BUS BAR ──► PSU negative terminal
NEMA 17 #6 ground ──┤
Arduino ground ─────┤
RPi ground ─────────┘

Never daisy-chain grounds. Motor return current must NOT flow through RPi ground plane.

RPi 5 GPIO (3.3V)
Logic Level Converter (bi-directional 3.3V ↔ 5V)
Arduino Mega (5V) ──── USB 2.0 (black port) ──── RPi USB hub
├──► STEP/DIR/EN ──► TMC2209 #1–6
├──► Limit Switch inputs (6×, NC wired, shielded twisted pair)
└──► HX711 (load cell amp) → SPI

RealSense D435 ──── USB 3.0 (blue port, direct to RPi) ──── RPi 5

[do not share hub with Arduino]

Limit Switch Wiring (NC — Fail-Safe)

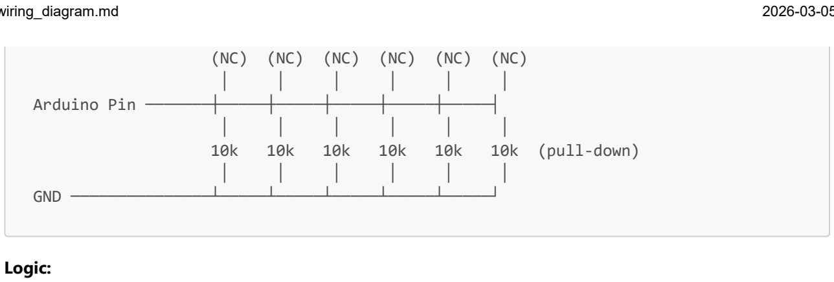
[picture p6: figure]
Arduino Pin ───────┼─────┼─────┼─────┼─────┼─────┤; 10k (pull-down); GND ───────────────┴─────┴─────┴─────┴─────┴─────┘; Logic:

Normal state (switch closed): Pin reads HIGH (5V through NC contact) Triggered OR wire break: Pin reads LOW (pull-down to GND)
LOW = STOP immediately — this is fail-safe

## EMI Prevention Checklist

Ferrite bead on Arduino ↔ RPi USB cable
1000µF cap on each NEMA 23 TMC2209 power input 1000µF cap on relay board 5V input
Twist motor wire pairs (A+/A- together, B+/B- together) Shielded twisted pair for all limit switch runs
Shield connected to star ground at ONE end only (PSU side) 50mm+ separation between power zone and logic zone RPi powered from dedicated 5V 3A PSU (not buck converter)

## E-Stop Wiring

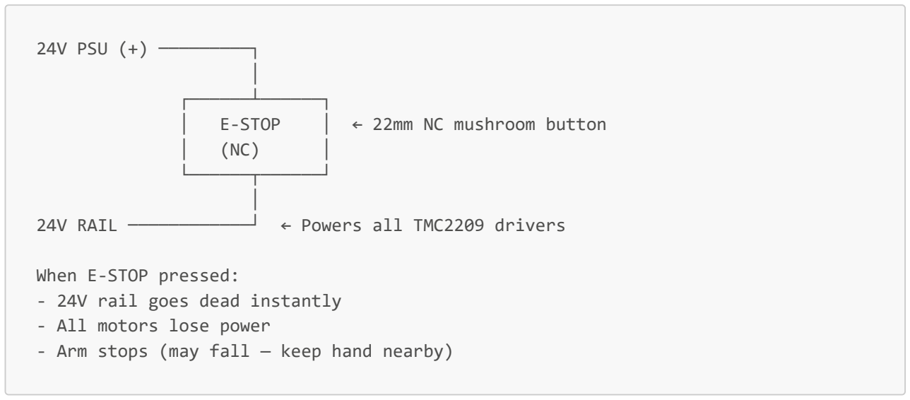
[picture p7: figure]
24V PSU (+) ─────────┐ │ ┌──────┴──────┐; E-STOP; │ ← 22mm NC mushroom button; When E-STOP pressed: - 24V rail goes dead instantly - All motors lose power

24V RAIL ────────────┘ ← Powers all TMC2209 drivers

- Arm stops (may fall — keep hand nearby)

Important: E-stop is hardware-level, not software. It physically disconnects 24V regardless of code state.

## Relay Board Trigger Timing

When activating multiple relays (e.g., at startup), stagger triggers by 50ms:

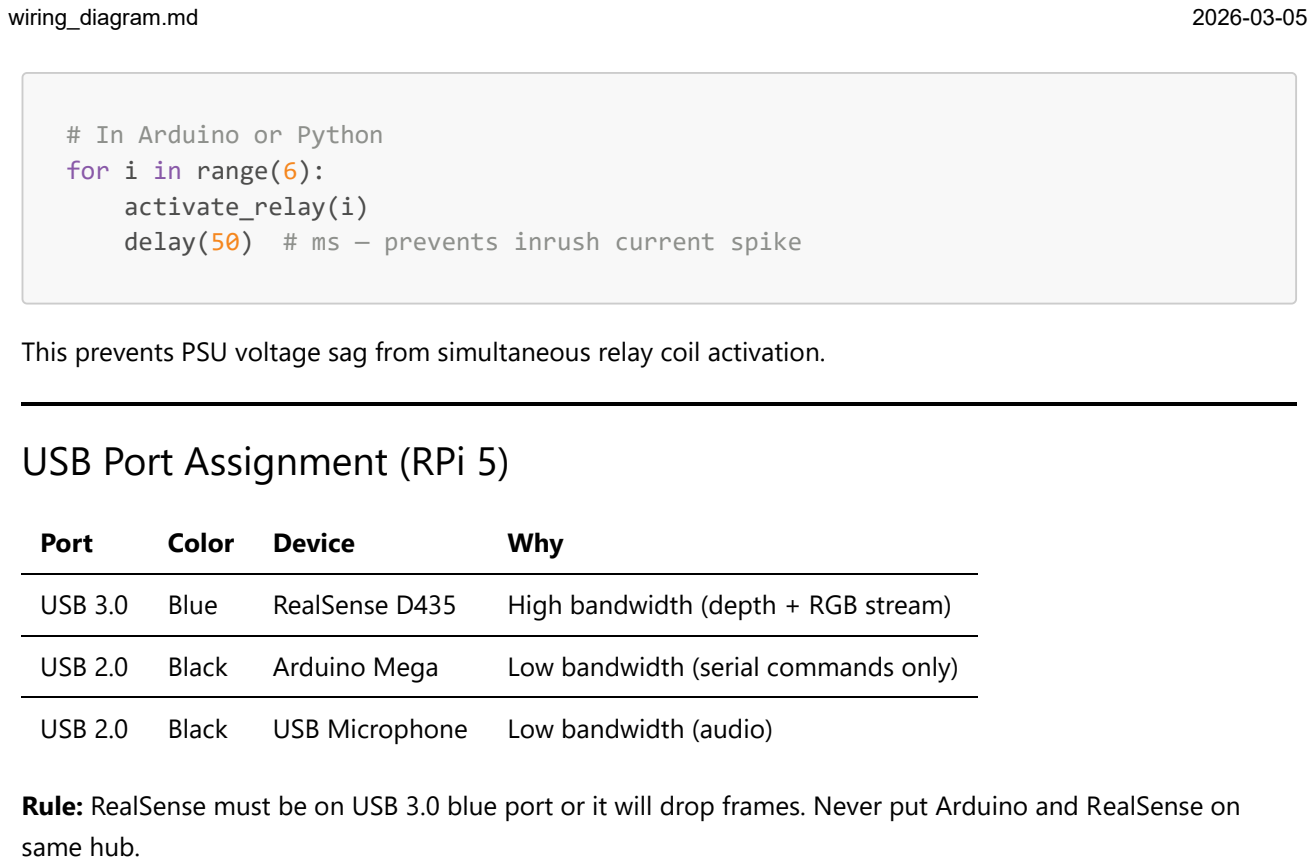
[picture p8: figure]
# In Arduino or Python for i in range(6): activate_relay(i); USB Port Assignment (RPi 5); Port; Color Device; Why; USB 2.0 Black; Arduino Mega; Low bandwidth (serial commands only); USB Microphone Low bandwidth (audio); same hub.

delay(50) # ms — prevents inrush current spike

This prevents PSU voltage sag from simultaneous relay coil activation.

USB 3.0 Blue | RealSense D435 | High bandwidth (depth + RGB stream)

Rule: RealSense must be on USB 3.0 blue port or it will drop frames. Never put Arduino and RealSense on

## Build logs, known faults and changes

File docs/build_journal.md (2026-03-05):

# ARTIC-6 — Build Journal

Progress log. Updated as the build moves forward.

---

## March 2026 — Phase 0: Planning & Engineering Review

### Week 1

**Progress:**
- Defined project scope: 6-DOF arm, 720mm reach, 1kg payload, voice-activated
- Researched motor options — decided on NEMA 23/17 + TMC2209 over hobby servos
- Chose local AI stack: Whisper + Ollama + YOLO v8 + ROS2 — zero paid APIs
- Completed full cost worksheet — all-in realistic budget ~$1,215
- Applied for Hack Club Blueprint funding ($380 requested)
- Applied for Fusion 360 student license — **approved same day**
- Created GitHub repository with full BOM, wiring notes, CAD spec

### Engineering Review (Critical Findings)

Ran deep engineering review before touching Fusion 360 or ordering anything.
Key discoveries that changed the design:

| Issue Found | Consequence if ignored | Fix Applied |
|---|---|---|
| NEMA 23 alone = 0.79Nm, need 7.06Nm | Arm cannot lift itself | 10:1 belt reduction added |
| Single 3mm plate twists over 350mm | Arm flexes and shakes at gripper | Sandwich construction (2 plates + 40mm standoffs) |
| PETG motor mounts soften at 80°C | Motor sinks into mount over time | Aluminum motor mounts |
| Standard GT2 belt stretches | Backlash — gripper position drifts | Steel-core GT2 belts |
| 608ZZ can't handle axial load at base | Base bearing fails under arm weight | Thrust bearing 51100 added to Axis 1 |
| NC vs NO limit switches | Wire breaks = arm drives into floor | All switches wired NC |
| Fixed motor mount holes | Can't tension belt later | Slotted holes in CAD |
| Unlimited rotation on Axis 1 | Internal cables wind up and snap | Hard stop tabs at ±170° in CAD |
| Star ground not planned | Motor noise crashes RPi / sensors | Star ground bus bar added |
| RealSense on shared USB | Bandwidth starves Arduino comms | RealSense → USB3, Arduino → USB2 |

**Lesson learned:** Every hour in planning saved at minimum one rebuild cycle.
The original v0.0 design would have failed at the shoulder immediately.

---

---

## March 4, 2026 — First CAD Session: SendCutSend DXFs + 3D Print Files

### What I Did Today

Generated production-ready DXF files for SendCutSend and my first 3D-printable STL. All aluminum parts are 3mm 6061-T6, cut with laser/waterjet (2D through-cuts only).

### Files Created

| File | Type | What It Is | Order Qty |
|---|---|---|---|
| `cad/baseplate.dxf` | SendCutSend | 250×250mm base plate — center shaft hole, NEMA 23 motor mount with slotted bolt holes for belt tensioning, cable pass-through, desk mounts, hard stop post, electronics tray holes, thrust bearing collar mount holes | 1× |
| `cad/link1_upper_arm.dxf` | SendCutSend | 350×60mm upper arm plate — dual 608ZZ bearing holes at each pivot, 4 pairs of M5 standoff holes, center cable channel, lightening holes, calibration notches | 2× (sandwich pair) |
| `cad/link2_forearm.dxf` | SendCutSend | 280×50mm forearm plate — same layout as Link 1 but narrower, 3 standoff pairs, RealSense USB-C strain relief slot | 2× (sandwich pair) |
| `cad/thrust_bearing_collar.stl` | 3D Print (PETG) | 44mm collar that captures the 51100 thrust bearing on the baseplate — replaces the 0.5mm recess that laser cutting can't do | 1× |

### Key Design Decisions Made

- **Thrust bearing seat problem solved:** SendCutSend can't cut partial-depth pockets (laser goes all the way through). Designed a 3D-printed PETG collar that bolts on top of the baseplate and captures the 51100 bearing in a 2mm recess. 3× M3 bolt holes match between collar and baseplate.
- **Motor mounts below baseplate:** NEMA 23 body hangs underneath, shaft comes up through 38.5mm pilot hole. 20T pulley on top drives 80T on turntable. Belt center-distance = 65mm, giving 145.8° belt wrap (above 120° minimum).
- **Slotted motor bolt holes:** 4.5×12mm stadium slots give ~7.5mm of travel to tension GT2 belt after assembly. Can't do this after cutting.
- **Link plates use sandwich construction:** Two identical plates spaced 40mm apart with M5 hex standoffs every ~90mm. Creates a rigid box section that resists the torsional twist a single 3mm plate can't handle.
- **Calibration notches on link plates:** 3mm semicircle cuts on bottom edge at 100mm and 250mm from shoulder end — alignment reference during assembly.

### Engineering Audit Results

Wrote and ran a full geometric audit script checking every hole diameter, edge clearance, feature overlap, and SendCutSend manufacturing limits.

**Bugs caught and fixed:**
1. Bearing collar bolt holes were only 1.3mm from outer edge → increased collar OD from 38mm to 44mm (now 4.3mm wall)
2. Calibration notches were 2mm diameter → below SendCutSend's 3mm minimum feature size → increased to 3mm
3. Lightening holes on link plates were sized too large (18mm) to actually fit → reduced to 12mm so they clear edges
4. Original calibration notches were floating inside the plate body instead of cutting the edge → fixed to semicircles on edge

**Final audit: 0 errors, 0 warnings.**

### What I Learned

- SendCutSend is 2D only — no pockets, no depth, everything goes through. Design around this by combining laser-cut plates with 3D-printed adapters.
- The "just put holes 20mm from the edge" advice I got from another AI was wrong. Every hole position needs to be driven by what it's for (motor bolt pattern, bearing spacing, etc.), not an arbitrary margin.
- Running an automated geometry audit before ordering is essential — caught 4 errors I would have paid $130+ to discover.
- Python + ezdxf can generate production-quality DXF files directly. All parameters are changeable at the top of each script — regenerate in seconds.

### What's NOT Done Yet (Don't Order Yet)

- **Shoulder joint brackets** — determine motor mount position on Link 1
- **Elbow joint brackets** — same for Link 2
- **Motor mounts** (6×) — L-brackets, depend on bracket geometry
- **3D assembly verification in Fusion 360** — must import DXFs, extrude, and confirm everything fits in 3D before sending to SendCutSend
- **Belt center-distance confirmation** — need physical pulleys in hand to verify 65mm assumption

### Priority: Order GT2 Pulleys Now

The 20T and 80T aluminum GT2 pulleys ($14 total from AliExpress) need to ship ASAP — 2-4 week delivery. They're needed to confirm belt center-distance before finalizing any DXF that has motor mount holes. Everything else is blocked until CAD is fully assembled in Fusion 360.

---

## Current Status

**Phase 0: Planning** — ✅ Complete

**Phase 1: CAD Design** — 🔄 In Progress
- [x] Base plate DXF generated and audited
- [x] Link 1 upper arm DXF generated and audited
- [x] Link 2 forearm DXF generated and audited
- [x] Thrust bearing collar STL generated
- [x] Imported DXFs into Fusion 360, extruded to 3mm
- [x] Got SendCutSend quote: ~$130 USD
- [ ] Design shoulder joint brackets
- [ ] Design elbow joint brackets
- [ ] Design motor mounts (6×)
- [ ] Full 3D assembly verification in Fusion 360
- [ ] Final SendCutSend order (after brackets + mounts designed)

**Phase 1.5: Firmware** — ✅ v0.1 Complete
- [x] config.h — pin assignments, speeds, accels, joint limits, gear ratios
- [x] stepper.h — AccelStepper wrapper, limit checking, e-stop
- [x] homing.h — limit switch homing (fast approach, back off, slow re-approach)
- [x] serial_protocol.h — plain text command parser (PING, MOVE, HOME, ESTOP, etc.)
- [x] artic6_firmware.ino — main sketch, compiles and ready to upload
- [ ] Upload to Arduino Mega and test serial comms
- [ ] TMC2209 UART configuration (future)

**Phase 2: Parts Ordering** — ⏳ Waiting for funds
- [ ] Order GT2 pulleys from AliExpress (critical path — 2-4 week shipping)
- [ ] Order remaining BOM items
- [ ] Submit SendCutSend order (after CAD fully verified)

---

## March 5, 2026 — Firmware Written + Project Review

### What I Did Today

Wrote the complete v0.1 firmware for the Arduino Mega — 5 files, fully functional stepper control with serial command interface. Also created an interactive arm layout visualization.

### Files Created

| File | What It Is |
|---|---|
| `firmware/artic6_firmware/config.h` | All pin assignments, motor speeds, accelerations, joint limits, gear ratios — single file to tune everything |
| `firmware/artic6_firmware/stepper.h` | AccelStepper wrapper — smooth acceleration, joint limit checking, e-stop, enable/disable per axis |
| `firmware/artic6_firmware/homing.h` | Limit switch homing — 3-phase (fast approach → back off → slow re-approach) for each axis |
| `firmware/artic6_firmware/serial_protocol.h` | Command parser — RPi sends text commands like `MOVE 2 45` over USB serial |
| `firmware/artic6_firmware/artic6_firmware.ino` | Main sketch — startup, loop, safety checks |
| `docs/arm_layout_visual.html` | Interactive side-view of assembled arm with movable shoulder/elbow sliders |

### Key Decisions

- **AccelStepper library** chosen for motor control — handles acceleration profiles, no manual timer math
- **Plain text serial protocol** (not JSON) — simpler to debug, type commands directly in Serial Monitor
- **Homing order: shoulder → elbow → base → wrist** — prevents collisions during homing sequence
- **100ms limit switch polling** during motion — safety net catches unexpected triggers
- **All motors disabled on power-up** — arm hangs limp until explicitly enabled, prevents surprises

### What I Learned

- DXF files being "2D" is correct — they're laser cutting profiles, the 3D structure comes from sandwich assembly
- 3mm 6061-T6 aluminum is the right thickness — sandwich construction with 40mm standoffs gives rigidity of much thicker material
- Firmware can be written and tested before any hardware arrives
- The material is 6061-T6 (not 6016 — that's an automotive alloy)

### Project Status Snapshot

- 3D printer arriving Friday
- No parts ordered yet (waiting for funds)
- GT2 pulleys are the critical path item (2-4 week AliExpress shipping)
- Hack Club funding ($380) — won't know until after March 31
- Fusion 360 open, DXFs imported and extruded, but brackets/mounts not designed yet
- Firmware ready to upload the moment an Arduino Mega is in hand

---

## Next Milestones

- [ ] Print thrust bearing collar in PETG (Friday, when printer arrives)
- [ ] Upload firmware to Arduino Mega, test PING/PONG
- [ ] Design shoulder + elbow joint brackets in Fusion 360
- [ ] Design motor mounts in Fusion 360
- [ ] Order GT2 pulleys ASAP (critical path)
- [ ] Get a multimeter
- [ ] Learn soldering basics (YouTube)
- [ ] Write Python serial bridge (RPi → Arduino)
- [ ] Full 3D assembly check in Fusion 360
- [ ] Submit SendCutSend order when funds + CAD ready

---

*Next session: Fusion 360 — design joint brackets and motor mounts*

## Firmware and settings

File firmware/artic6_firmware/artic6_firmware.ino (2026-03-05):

// ============================================================
//  ARTIC-6 FIRMWARE — Main Sketch
//  Arduino Mega 2560 + 6× TMC2209 stepper drivers
//
//  REQUIRED LIBRARY:
//    AccelStepper by Mike McCauley
//    Install: Arduino IDE → Sketch → Include Library →
//             Manage Libraries → search "AccelStepper" → Install
//
//  UPLOAD:
//    Board: "Arduino Mega or Mega 2560"
//    Processor: "ATmega2560"
//    Port: (whatever COM port shows up)
//
//  SERIAL MONITOR:
//    115200 baud, Newline line ending
//    Type "PING" and hit enter — should respond "OK PONG"
// ============================================================

#include "config.h"
#include "stepper.h"
#include "homing.h"
#include "serial_protocol.h"

// Status LED — blinks to show firmware is running
#define LED_PIN 13  // Built-in LED on Mega (shared with DIR_PIN_6)
// Note: LED_PIN conflicts with DIR_PIN_6. The LED blink is disabled
// once motors are enabled. This is fine — you'll know it's alive
// from serial responses.

unsigned long lastStatusTime = 0;
#define STATUS_INTERVAL_MS 100  // Check limit switches every 100ms

void setup() {
  // Start serial to RPi
  Serial.begin(SERIAL_BAUD);
  while (!Serial) { ; } // Wait for USB serial (only needed on some boards)

  Serial.println(F(""));
  Serial.println(F("============================="));
  Serial.println(F("  ARTIC-6 Firmware v0.1"));
  Serial.println(F("  6-DOF Robot Arm Controller"));
  Serial.println(F("============================="));
  Serial.println(F(""));

  // Initialize limit switch pins (INPUT — external pull-down resistors)
  for (uint8_t i = 0; i < NUM_AXES; i++) {
    pinMode(LIMIT_PINS[i], INPUT);
  }

  // Initialize stepper motors (all disabled/free on startup)
  steppersInit();

  Serial.println(F("Motors initialized (disabled)"));
  Serial.println(F("Commands: PING, ENABLE, HOME, MOVE, POS, STATUS, STOP, ESTOP"));
  Serial.println(F("Type ENABLE then HOME before moving."));
  Serial.println(F(""));
  Serial.println(F("OK READY"));

  lastCmdTime = millis();
}

void loop() {
  // 1. Check for serial commands from RPi
  serialPoll();

  // 2. Run stepper motors (generates step pulses)
  //    This MUST be called as fast as possible for smooth motion
  steppersRun();

  // 3. Periodic safety checks
  if (millis() - lastStatusTime > STATUS_INTERVAL_MS) {
    lastStatusTime = millis();

    // Check limit switches during motion — stop axis if triggered
    if (!emergencyStop) {
      for (uint8_t i = 0; i < NUM_AXES; i++) {
        if (steppers[i].isRunning() && limitTriggered(i)) {
          steppers[i].stop();
          steppers[i].setCurrentPosition(steppers[i].currentPosition());
          Serial.print(F("WARN limit hit axis "));
          Serial.println(i + 1);
        }
      }
    }

    // Watchdog
    watchdogCheck();
  }
}

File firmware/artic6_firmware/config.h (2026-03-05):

#ifndef CONFIG_H
#define CONFIG_H

// ============================================================
//  ARTIC-6 FIRMWARE CONFIGURATION
//  Arduino Mega 2560 + TMC2209 drivers
//  All pin assignments match wiring_diagram.md
// ============================================================

// --- Number of axes ---
#define NUM_AXES 6

// --- STEP pins (D2-D7) ---
// One pulse on STEP = one microstep movement
#define STEP_PIN_1  2   // Axis 1: Base rotation (NEMA 23)
#define STEP_PIN_2  3   // Axis 2: Shoulder      (NEMA 23)
#define STEP_PIN_3  4   // Axis 3: Elbow          (NEMA 23)
#define STEP_PIN_4  5   // Axis 4: Wrist pitch    (NEMA 17)
#define STEP_PIN_5  6   // Axis 5: Wrist roll     (NEMA 17)
#define STEP_PIN_6  7   // Axis 6: Gripper rot    (NEMA 17)

const uint8_t STEP_PINS[NUM_AXES] = {
  STEP_PIN_1, STEP_PIN_2, STEP_PIN_3,
  STEP_PIN_4, STEP_PIN_5, STEP_PIN_6
};

// --- DIR pins (D8-D13) ---
// HIGH/LOW sets rotation direction
#define DIR_PIN_1   8
#define DIR_PIN_2   9
#define DIR_PIN_3   10
#define DIR_PIN_4   11
#define DIR_PIN_5   12
#define DIR_PIN_6   13

const uint8_t DIR_PINS[NUM_AXES] = {
  DIR_PIN_1, DIR_PIN_2, DIR_PIN_3,
  DIR_PIN_4, DIR_PIN_5, DIR_PIN_6
};

// --- ENABLE pins (D22-D27) ---
// LOW = motor energized, HIGH = motor free (TMC2209 convention)
#define EN_PIN_1    22
#define EN_PIN_2    23
#define EN_PIN_3    24
#define EN_PIN_4    25
#define EN_PIN_5    26
#define EN_PIN_6    27

const uint8_t EN_PINS[NUM_AXES] = {
  EN_PIN_1, EN_PIN_2, EN_PIN_3,
  EN_PIN_4, EN_PIN_5, EN_PIN_6
};

// --- LIMIT SWITCH pins (D28-D33) ---
// Wired NC (normally closed) with 10k pull-down
// HIGH = normal (switch closed), LOW = triggered or wire broken = STOP
#define LIMIT_PIN_1  28
#define LIMIT_PIN_2  29
#define LIMIT_PIN_3  30
#define LIMIT_PIN_4  31
#define LIMIT_PIN_5  32
#define LIMIT_PIN_6  33

const uint8_t LIMIT_PINS[NUM_AXES] = {
  LIMIT_PIN_1, LIMIT_PIN_2, LIMIT_PIN_3,
  LIMIT_PIN_4, LIMIT_PIN_5, LIMIT_PIN_6
};

// --- MOTOR PARAMETERS ---

// Microstep setting on TMC2209 (set via MS1/MS2 pins or UART)
// 8 microsteps is a good balance of smoothness vs speed
#define MICROSTEPS 8

// Steps per revolution: 200 full steps × microsteps
#define STEPS_PER_REV (200L * MICROSTEPS)  // = 1600

// Belt reduction ratios (motor turns : joint turns)
// 20T motor pulley → 80T joint pulley = 4:1 per stage
// Axes 1-3: two-stage 4:1 = 16:1 (NEMA 23)
// Axes 4-6: single-stage or direct (NEMA 17) — TBD after wrist design
#define REDUCTION_1  16.0   // Base rotation
#define REDUCTION_2  16.0   // Shoulder
#define REDUCTION_3  16.0   // Elbow
#define REDUCTION_4   4.0   // Wrist pitch (single stage)
#define REDUCTION_5   4.0   // Wrist roll
#define REDUCTION_6   1.0   // Gripper (direct drive or low ratio)

const float REDUCTIONS[NUM_AXES] = {
  REDUCTION_1, REDUCTION_2, REDUCTION_3,
  REDUCTION_4, REDUCTION_5, REDUCTION_6
};

// Steps per degree of joint rotation
// = (STEPS_PER_REV * reduction) / 360
// Axis 1: (1600 * 16) / 360 = 71.11 steps/degree
// Axis 2: same
// Axis 4: (1600 * 4) / 360 = 17.78 steps/degree

// Max speeds (steps/sec) — conservative starting values
// NEMA 23 at 2.8A can typically do ~2000 steps/sec at 8 microsteps
// NEMA 17 at 2A can do ~3000 steps/sec
#define MAX_SPEED_1     1500   // Base (slow — heavy inertia)
#define MAX_SPEED_2     1200   // Shoulder (slowest — full arm load)
#define MAX_SPEED_3     1500   // Elbow
#define MAX_SPEED_4     2500   // Wrist pitch
#define MAX_SPEED_5     2500   // Wrist roll
#define MAX_SPEED_6     3000   // Gripper

const long MAX_SPEEDS[NUM_AXES] = {
  MAX_SPEED_1, MAX_SPEED_2, MAX_SPEED_3,
  MAX_SPEED_4, MAX_SPEED_5, MAX_SPEED_6
};

// Max acceleration (steps/sec²)
// Lower = smoother but slower. Higher = more responsive but can skip steps.
#define MAX_ACCEL_1     800
#define MAX_ACCEL_2     600   // Shoulder needs gentle accel (heavy load)
#define MAX_ACCEL_3     800
#define MAX_ACCEL_4     1500
#define MAX_ACCEL_5     1500
#define MAX_ACCEL_6     2000

const long MAX_ACCELS[NUM_AXES] = {
  MAX_ACCEL_1, MAX_ACCEL_2, MAX_ACCEL_3,
  MAX_ACCEL_4, MAX_ACCEL_5, MAX_ACCEL_6
};

// Joint limits (degrees from home position)
// Axis 1 has hard stops at ±170°
#define JOINT_MIN_1   -170.0
#define JOINT_MAX_1    170.0
#define JOINT_MIN_2    -30.0   // Shoulder can't go far behind
#define JOINT_MAX_2    120.0
#define JOINT_MIN_3   -120.0   // Elbow folds back
#define JOINT_MAX_3     30.0
#define JOINT_MIN_4    -90.0
#define JOINT_MAX_4     90.0
#define JOINT_MIN_5   -180.0
#define JOINT_MAX_5    180.0
#define JOINT_MIN_6    -90.0
#define JOINT_MAX_6     90.0

const float JOINT_MINS[NUM_AXES] = {
  JOINT_MIN_1, JOINT_MIN_2, JOINT_MIN_3,
  JOINT_MIN_4, JOINT_MIN_5, JOINT_MIN_6
};
const float JOINT_MAXS[NUM_AXES] = {
  JOINT_MAX_1, JOINT_MAX_2, JOINT_MAX_3,
  JOINT_MAX_4, JOINT_MAX_5, JOINT_MAX_6
};
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

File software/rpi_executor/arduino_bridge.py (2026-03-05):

#!/usr/bin/env python3
"""
ARTIC-6 Serial Bridge — RPi 5 ↔ Arduino Mega

Sends plain-text commands over USB serial and parses responses.
Matches firmware serial_protocol.h exactly.

Usage:
    from arduino_bridge import ArmBridge

    arm = ArmBridge()          # auto-detects port
    arm.ping()                 # True if connected
    arm.enable()
    arm.home()
    arm.move(2, 45.0)          # shoulder to 45°
    arm.move_all(0, 45, -30, 0, 0, 0)
    print(arm.get_pos())       # [0.0, 45.0, -30.0, 0.0, 0.0, 0.0]
    arm.estop()
"""

import serial
import serial.tools.list_ports
import time
import threading


class ArmBridge:
    NUM_AXES = 6

    def __init__(self, port=None, baudrate=115200, timeout=2.0):
        if port is None:
            port = self._find_port()
        self._ser = serial.Serial(port, baudrate, timeout=timeout)
        self._lock = threading.Lock()
        time.sleep(2)  # Arduino resets on serial open

    # ---- Auto-detect Arduino Mega ----
    @staticmethod
    def _find_port():
        for p in serial.tools.list_ports.comports():
            desc = (p.description or "").lower()
            vid_pid = (p.hwid or "").upper()
            if "mega" in desc or "2560" in desc or "2341:0042" in vid_pid:
                return p.device
        # Fallback: first available serial port
        ports = list(serial.tools.list_ports.comports())
        if ports:
            return ports[0].device
        raise ConnectionError("No serial port found — is the Arduino plugged in?")

    # ---- Low-level send/receive ----
    def _send(self, cmd, timeout=10.0):
        """Send command, return response line."""
        with self._lock:
            self._ser.reset_input_buffer()
            self._ser.write((cmd.strip() + "\n").encode("ascii"))
            self._ser.flush()
            deadline = time.monotonic() + timeout
            while time.monotonic() < deadline:
                line = self._ser.readline().decode("ascii", errors="replace").strip()
                if line:
                    return line
            raise TimeoutError(f"No response to: {cmd}")

    def _send_ok(self, cmd, timeout=10.0):
        """Send command, expect OK response. Raises on ERR."""
        resp = self._send(cmd, timeout)
        if resp.startswith("OK"):
            return resp
        raise RuntimeError(f"Command '{cmd}' failed: {resp}")

    # ---- Commands ----
    def ping(self):
        try:
            return self._send("PING", timeout=3.0) == "OK PONG"
        except (TimeoutError, OSError):
            return False

    def enable(self):
        return self._send_ok("ENABLE")

    def disable(self):
        return self._send_ok("DISABLE")

    def home(self, timeout=120.0):
        """Home all axes. Long timeout — homing takes a while."""
        return self._send_ok("HOME", timeout=timeout)

    def home_axis(self, axis, timeout=60.0):
        """Home single axis (1-6)."""
        if not 1 <= axis <= self.NUM_AXES:
            raise ValueError(f"Axis must be 1-{self.NUM_AXES}")
        return self._send_ok(f"HOMEA {axis}", timeout=timeout)

    def move(self, axis, degrees):
        """Move single axis to absolute angle (1-6)."""
        if not 1 <= axis <= self.NUM_AXES:
            raise ValueError(f"Axis must be 1-{self.NUM_AXES}")
        return self._send_ok(f"MOVE {axis} {degrees:.2f}")

    def move_relative(self, axis, degrees):
        """Move single axis by relative angle (1-6)."""
        if not 1 <= axis <= self.NUM_AXES:
            raise ValueError(f"Axis must be 1-{self.NUM_AXES}")
        return self._send_ok(f"MOVR {axis} {degrees:.2f}")

    def move_all(self, a1, a2, a3, a4, a5, a6):
        """Move all 6 axes to absolute positions."""
        return self._send_ok(f"MOVA {a1:.2f} {a2:.2f} {a3:.2f} {a4:.2f} {a5:.2f} {a6:.2f}")

    def stop(self):
        return self._send_ok("STOP")

    def estop(self):
        return self._send_ok("ESTOP")

    def reset(self):
        """Reset from e-stop. Must re-home after."""
        return self._send_ok("RESET")

    def get_pos(self):
        """Return list of 6 joint positions in degrees."""
        resp = self._send("POS")
        if not resp.startswith("POS"):
            raise RuntimeError(f"Unexpected POS response: {resp}")
        parts = resp.split()[1:]
        return [float(p) for p in parts]

    def get_status(self):
        """Return parsed status dict."""
        resp = self._send("STATUS")
        if not resp.startswith("STATUS"):
            raise RuntimeError(f"Unexpected STATUS response: {resp}")
        status = {}
        for token in resp.split()[1:]:
            if "=" in token:
                k, v = token.split("=", 1)
                if v in ("YES", "NO"):
                    status[k] = v == "YES"
                elif "," in v:
                    status[k] = [float(x) for x in v.split(",")]
                else:
                    status[k] = v
        return status

    def wait_until_idle(self, poll_interval=0.2, timeout=120.0):
        """Block until all axes stop moving."""
        deadline = time.monotonic() + timeout
        while time.monotonic() < deadline:
            st = self.get_status()
            if not st.get("moving", False):
                return True
            time.sleep(poll_interval)
        raise TimeoutError("Arm still moving after timeout")

    def close(self):
        if self._ser and self._ser.is_open:
            self._ser.close()

    def __enter__(self):
        return self

    def __exit__(self, *args):
        self.close()


# ---- Quick CLI test ----
if __name__ == "__main__":
    import sys

    port = sys.argv[1] if len(sys.argv) > 1 else None
    with ArmBridge(port) as arm:
        print(f"Connected: {arm.ping()}")
        print(f"Status:    {arm.get_status()}")
        print(f"Position:  {arm.get_pos()}")

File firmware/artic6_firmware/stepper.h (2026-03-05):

#ifndef STEPPER_H
#define STEPPER_H

#include <AccelStepper.h>
#include "config.h"

// ============================================================
//  STEPPER MOTOR CONTROL
//  Uses AccelStepper library for smooth acceleration/decel
//  Install: Arduino IDE → Library Manager → "AccelStepper"
// ============================================================

// AccelStepper instances — one per axis
// Type 1 = driver mode (STEP + DIR pins only, driver handles coils)
AccelStepper steppers[NUM_AXES] = {
  AccelStepper(AccelStepper::DRIVER, STEP_PIN_1, DIR_PIN_1),
  AccelStepper(AccelStepper::DRIVER, STEP_PIN_2, DIR_PIN_2),
  AccelStepper(AccelStepper::DRIVER, STEP_PIN_3, DIR_PIN_3),
  AccelStepper(AccelStepper::DRIVER, STEP_PIN_4, DIR_PIN_4),
  AccelStepper(AccelStepper::DRIVER, STEP_PIN_5, DIR_PIN_5),
  AccelStepper(AccelStepper::DRIVER, STEP_PIN_6, DIR_PIN_6),
};

// Current joint positions in degrees (updated after homing + moves)
float jointPositions[NUM_AXES] = {0, 0, 0, 0, 0, 0};

// Whether each axis has been homed
bool axisHomed[NUM_AXES] = {false, false, false, false, false, false};

// Emergency stop flag
volatile bool emergencyStop = false;

// ---- Convert degrees to steps for a given axis ----
long degreesToSteps(uint8_t axis, float degrees) {
  if (axis >= NUM_AXES) return 0;
  float stepsPerDeg = (STEPS_PER_REV * REDUCTIONS[axis]) / 360.0;
  return (long)(degrees * stepsPerDeg);
}

// ---- Convert steps to degrees for a given axis ----
float stepsToDegrees(uint8_t axis, long steps) {
  if (axis >= NUM_AXES) return 0;
  float stepsPerDeg = (STEPS_PER_REV * REDUCTIONS[axis]) / 360.0;
  return (float)steps / stepsPerDeg;
}

// ---- Initialize all steppers ----
void steppersInit() {
  for (uint8_t i = 0; i < NUM_AXES; i++) {
    // Set enable pins
    pinMode(EN_PINS[i], OUTPUT);
    digitalWrite(EN_PINS[i], HIGH);  // HIGH = disabled (motors free)

    // Configure AccelStepper
    steppers[i].setMaxSpeed(MAX_SPEEDS[i]);
    steppers[i].setAcceleration(MAX_ACCELS[i]);
    steppers[i].setEnablePin(EN_PINS[i]);
    steppers[i].setPinsInverted(false, false, true); // EN is active LOW
    steppers[i].setCurrentPosition(0);
  }
}

// ---- Enable/disable individual axis ----
void enableAxis(uint8_t axis) {
  if (axis < NUM_AXES) {
    digitalWrite(EN_PINS[axis], LOW);  // LOW = motor energized
  }
}

void disableAxis(uint8_t axis) {
  if (axis < NUM_AXES) {
    digitalWrite(EN_PINS[axis], HIGH); // HIGH = motor free
  }
}

// ---- Enable/disable ALL axes ----
void enableAllAxes() {
  for (uint8_t i = 0; i < NUM_AXES; i++) enableAxis(i);
}

void disableAllAxes() {
  for (uint8_t i = 0; i < NUM_AXES; i++) disableAxis(i);
}

// ---- Check if target angle is within joint limits ----
bool withinLimits(uint8_t axis, float degrees) {
  if (axis >= NUM_AXES) return false;
  return (degrees >= JOINT_MINS[axis] && degrees <= JOINT_MAXS[axis]);
}

// ---- Move single axis to absolute angle (degrees) ----
// Returns false if out of limits or axis not homed
bool moveAxisTo(uint8_t axis, float degrees) {
  if (axis >= NUM_AXES) return false;
  if (!axisHomed[axis]) return false;
  if (!withinLimits(axis, degrees)) return false;
  if (emergencyStop) return false;

  long targetSteps = degreesToSteps(axis, degrees);
  steppers[axis].moveTo(targetSteps);
  return true;
}

// ---- Move single axis by relative degrees ----
bool moveAxisBy(uint8_t axis, float deltaDegrees) {
  if (axis >= NUM_AXES) return false;
  float newPos = jointPositions[axis] + deltaDegrees;
  return moveAxisTo(axis, newPos);
}

// ---- Check if any axis is still moving ----
bool anyAxisMoving() {
  for (uint8_t i = 0; i < NUM_AXES; i++) {
    if (steppers[i].isRunning()) return true;
  }
  return false;
}

// ---- Run all steppers (call this in loop() as fast as possible) ----
// Returns true if any axis is still moving
bool steppersRun() {
  if (emergencyStop) return false;

  bool moving = false;
  for (uint8_t i = 0; i < NUM_AXES; i++) {
    if (steppers[i].run()) {
      moving = true;
    }
  }

  // Update joint positions from step counters
  for (uint8_t i = 0; i < NUM_AXES; i++) {
    jointPositions[i] = stepsToDegrees(i, steppers[i].currentPosition());
  }

  return moving;
}

// ---- Stop all axes immediately ----
void stopAllAxes() {
  for (uint8_t i = 0; i < NUM_AXES; i++) {
    steppers[i].stop();                   // Decelerate to stop
    steppers[i].setCurrentPosition(        // Keep current position
      steppers[i].currentPosition()
    );
  }
}

// ---- Emergency stop — kill everything ----
void triggerEstop() {
  emergencyStop = true;
  for (uint8_t i = 0; i < NUM_AXES; i++) {
    steppers[i].setSpeed(0);
    steppers[i].moveTo(steppers[i].currentPosition());
  }
  disableAllAxes();
}

// ---- Reset from e-stop (requires re-homing) ----
void resetEstop() {
  emergencyStop = false;
  for (uint8_t i = 0; i < NUM_AXES; i++) {
    axisHomed[i] = false;
  }
}

#endif // STEPPER_H

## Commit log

2026-03-05 Initial commit: ARTIC-6 project structure with docs, BOM, wiring diagrams
2026-03-05 Switch to AliExpress pricing ( vs ), add personal background (14yo, 824AI), update all links
2026-03-05 Add firmware v0.1, CAD files, DXF generators, and build journal update
    - Firmware: complete Arduino Mega stepper control (AccelStepper)
    - config.h: pin defs, speeds, joint limits, gear ratios
    - stepper.h: motor control with acceleration profiles
    - homing.h: 3-phase limit switch homing
    - serial_protocol.h: text command interface (MOVE, HOME, ESTOP, etc.)
    - artic6_firmware.ino: main sketch ready to upload
    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
    [baseplate.dxf, link1_upper_arm.dxf, link2_forearm.dxf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]
2026-03-05 Add bom.csv, wiring diagram SVG, and README overhaul for Hack Club Blueprint
    - bom.csv: root-level CSV with all parts, quantities, prices, and direct shopping links
    - docs/wiring_diagram.svg: visual wiring diagram showing power zone, logic zone, star ground, all 6 TMC2209 drivers, Arduino Mega, RPi 5, and safety systems
    - README.md: complete overhaul hero description, hardware specs table, firmware command examples, BOM summary table, wiring diagram embedded, proper repo structure, budget breakdown with updated AliE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
    [bom.csv]
2026-03-05 Add wiring PDF link to README for Blueprint reviewers
2026-03-05 Add Python serial bridge for RPi-to-Arduino communication
